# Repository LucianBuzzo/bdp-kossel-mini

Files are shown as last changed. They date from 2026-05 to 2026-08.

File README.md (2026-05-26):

# BDP Kossel Mini

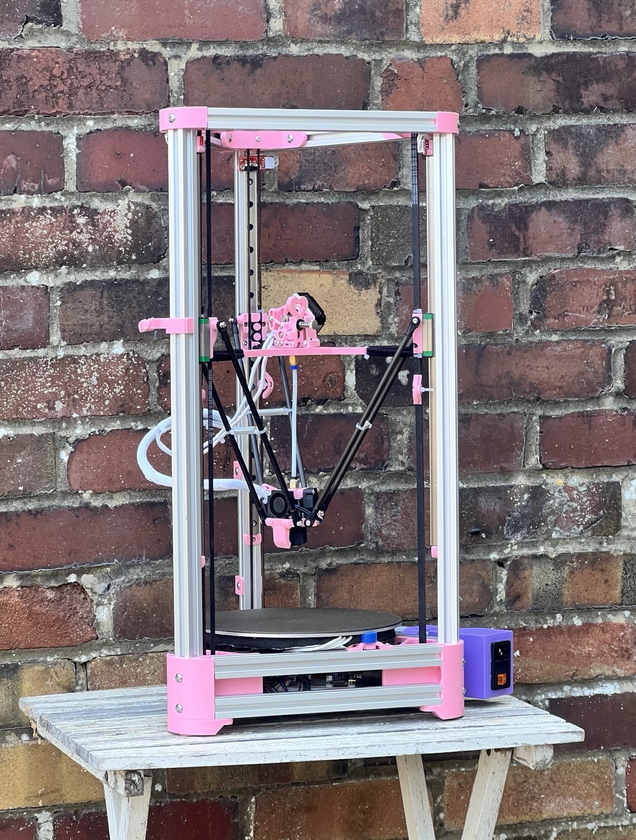
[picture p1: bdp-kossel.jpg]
BDP Kossel Mini delta printer


A modern take on the Kossel Mini delta printer using 2020 extrusions, running on an SKR Pico, and a Raspberry Pi Zero, powered by a meanwell UHP-350-24 PSU.

## Assembly

The major components of the printer are split into separate folders. Follow the instructions contained in each of them:
- [Chassis](./models/chassis/README.md)
- [Effector](./models/effector/README.md)
- [Extruder](./models/extruder/sherpa-extra-lovely/README.md)
- [Motion](./models/motion/README.md)
- [PSU](./models/PSU/README.md)

## Bill of Materials

The full bill of materials is compiled from component BOM CSV files in [`bom/`](./bom/).

See the generated [compiled BOM](./bom/README.md) or [combined CSV](./bom/combined.csv).

## Design Source and Exports

The canonical CAD source for this project is the linked Tinkercad design in each component README.

The STL files in this repository are exported from those Tinkercad designs and included for convenience so a known buildable version is available without needing to re-export the CAD.

To modify a part, update the relevant Tinkercad design, export new STL files, replace the files in this repository, and update the component README if the change affects print count, assembly, or the BOM.

## License

Original BDP Kossel Mini content is licensed under the [Creative Commons Attribution-ShareAlike 4.0 International License](./LICENSE).

Some included models are remixes or reused parts with their own license terms. See [THIRD_PARTY_LICENSES.md](./THIRD_PARTY_LICENSES.md) for attribution and per-file licensing.

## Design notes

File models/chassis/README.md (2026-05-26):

# Chassis

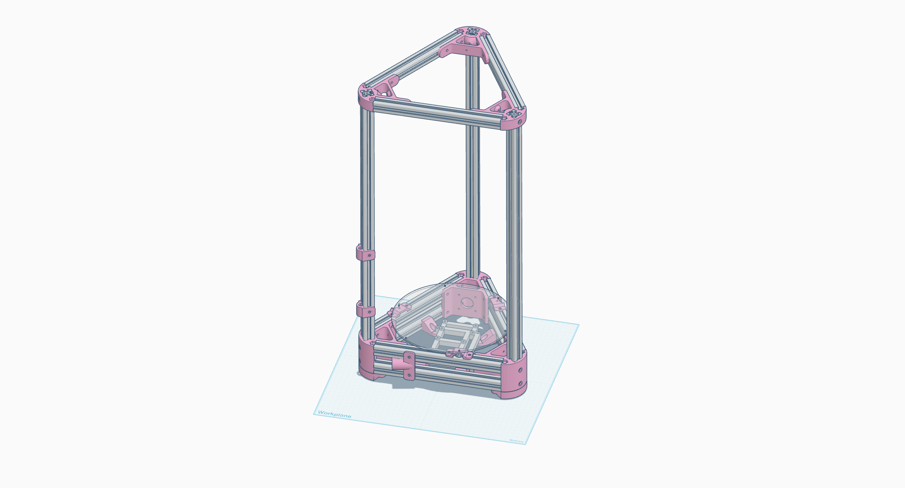
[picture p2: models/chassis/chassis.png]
Chassis


The chassis is designed around the original Kossel 2020 designs.
You'll need 3 x `frame-top.stl`, 3 x `frame-motor.stl` and 3 x `foot.stl` to print the frame.

For mounting the bed, print 3 x `bed-mount-base.stl` and 3 x `bed-mount-knob.stl`.

If you want to use the effector umbilical cable guides, print 2 x `cable-guide-tower.stl` and 1 x `cable-guide-base.stl`.

The electronics mount in the base, and are designed to fit the SKR Pico and a Raspberry Pi Zero. You'll need two `electronics-mount-front.stl` and two `electronics-mount-back.stl`. These could be the same file, but I haven't done the design work to make them the same yet.

The MCU mount plate is the "no inserts" variant of [Kanrog's Rook Mk1 design](https://www.printables.com/model/388353-rook-mk1-skr-pico-pi-zero-adapter/files).

## Bill of Materials

See the [chassis BOM](../../bom/chassis.csv) and the generated [compiled BOM](../../bom/README.md).

## Design Source

https://www.tinkercad.com/things/ggqOKI0i9KW-bdp-chassis

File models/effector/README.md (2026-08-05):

# Effector

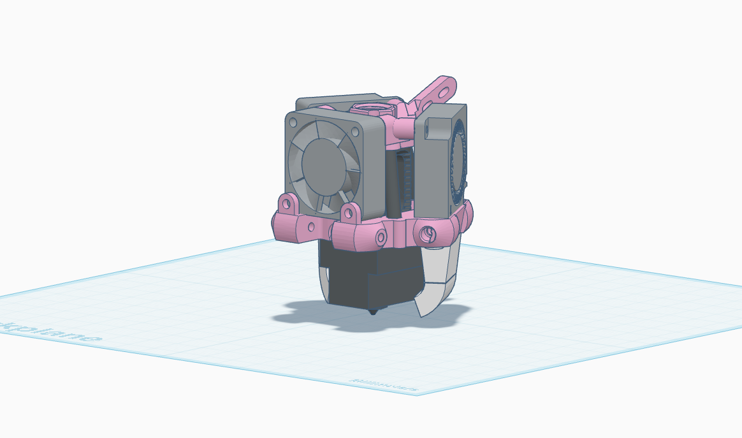
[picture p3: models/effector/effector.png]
Effector


The BDP effector is built around the original Kossel 2020 design, retaining the same arm spacing.
It's designed around the Triangle Lab Dragon Ace Volcano hotend ([This one specifically](https://jb3d.uk/product/dav/)), but could be adapted to support other hotends with the same mounting pattern by modifying the Z height of the cooling ducts.
Cooling is provided by a 3010 axial fan for the hotend, and two 3010 blower fans for part cooling.
Assembly also requires three 4mmx30mm Carbon Fiber Tubes.

## Bill of Materials

See the [effector BOM](../../bom/effector.csv) and the generated [compiled BOM](../../bom/README.md).

## Assembly Guide

1. Print the following parts:
    - `top-plate.stl` (x1)
    - `bottom-plate.stl` (x1)
    - `duct.stl` (x2)
    - `glue-up-jig.stl` (x1)
2. Cut the carbon fiber tubes to 30mm, and clean the ends with a file or sandpaper. Make sure to wear a mask and gloves when working with carbon fiber, as the dust is nasty and makes your skin itch! I recommend keeping everything wet when cutting and sanding to minimize dust.
3. Bolt the top and bottom plate to the glue up jig. This will keep the two plates perfectly parallel while you glue the carbon fiber tubes in place.
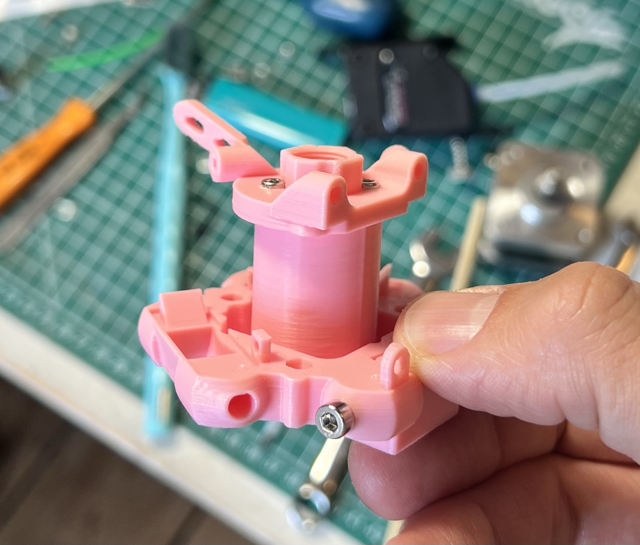
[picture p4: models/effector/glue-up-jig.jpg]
Glue up jig

4. Mix up your epoxy and apply a small amount to the tube socket in the top plate, and a small amount to the bottom end of the carbon fiber tube. Slide the tube in through the hole in the bottom plate and insert the tube into the socket in the top plate, ensuring it's firmly seated, then wipe away any excess epoxy. Repeat for all three tubes.
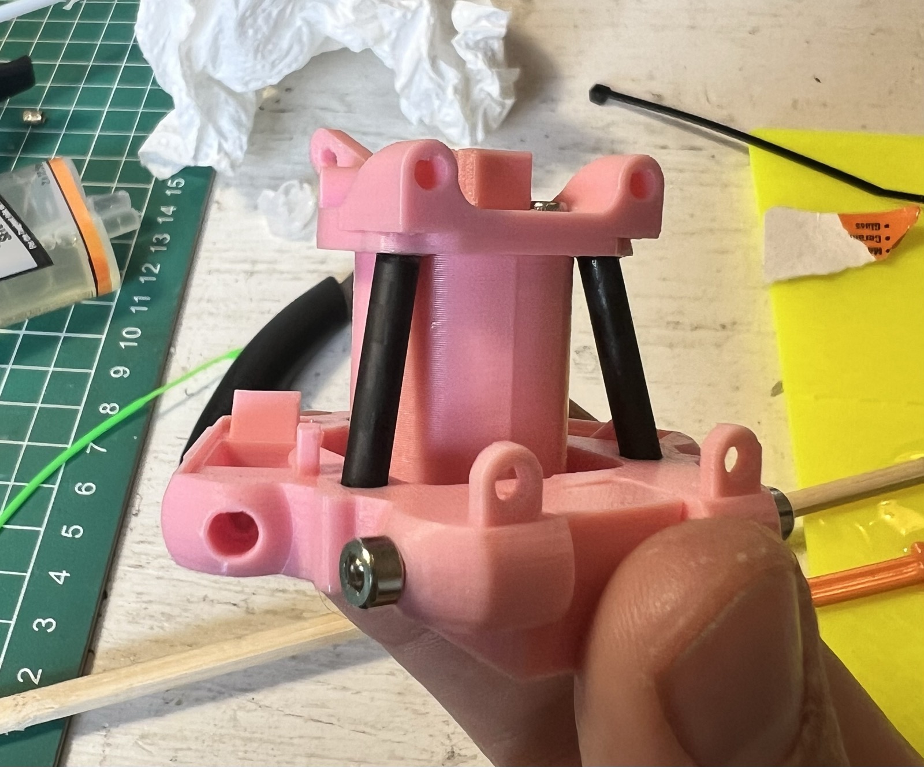
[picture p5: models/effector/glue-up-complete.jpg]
Glue up complete

5. Let the epoxy cure for at least 24 hours, then remove the glue up jig.
6. Press the M3 heat set inserts into the lateral con rod sockets on the bottom plate.
7. Press the M2 heat set inserts into the duct mounting holes on the underside of the bottom plate.
8. Mount the hotend to the top plate using the M2.5 hex bolts. You will need to route the hotend wires through the gap between the top and bottom plates, with each wire going either side of the carbon fiber tube.
9. Mount the axial fan to the bottom plate using the M3x12mm hex bolts and the M3 square nuts.
10. Mount the blower fans to the bottom plate using the M2.5 hex bolts.
11. Mount the ducts to the bottom plate using the M2 hex bolts.
12. Route the fan and thermistor wires through the gap between the top and bottom plates. 
13. Finish with some nice cable sleeve and zip tie to the cable relief points on the top plate, and you're done!

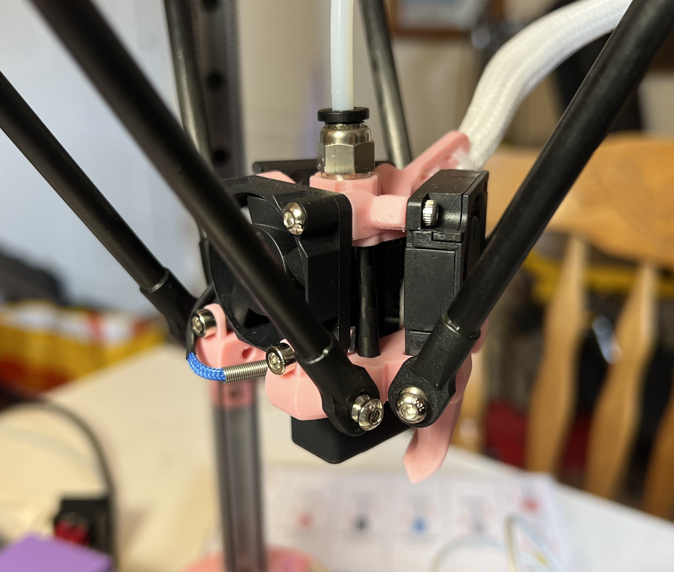
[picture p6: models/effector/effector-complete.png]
Assembled effector


## Design Source

https://www.tinkercad.com/things/bwVs2w1J2AP-bdp-effector

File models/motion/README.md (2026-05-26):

# Motion System

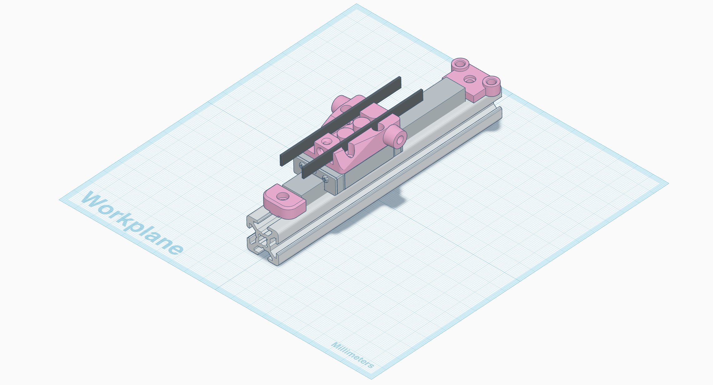
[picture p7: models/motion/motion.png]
Motion system render


The motion system on the BDP uses 6mm belt, 300mm long MGN12H linear rails, mechanical endstop switches and on-belt tensioners.

You will need to print 3 each of `carriage.stl`, `tensioner.stl`, `endstop-mount.stl` and `mgn12-endstop.stl`.

The carriages use m3 6mm heat seat inserts, and the endstop mounts use m3 4mm heat seat inserts. The endstops are designed around the RepRap/makerbot style endstop switches.

The MGN12 endstop is [vale075's design from printables](https://www.printables.com/model/345798-mgn12-rail-stopperendstop), and the tensioner is [Kiolia's universal adjustable belt tensioner](https://www.printables.com/model/157225-universal-adjustable-belt-tensioner), also from printables.

## Bill of Materials

See the [motion system BOM](../../bom/motion.csv) and the generated [compiled BOM](../../bom/README.md).

## Design Source

https://www.tinkercad.com/things/a9pKTf634uS-bdp-motion-system

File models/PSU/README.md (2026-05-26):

# PSU

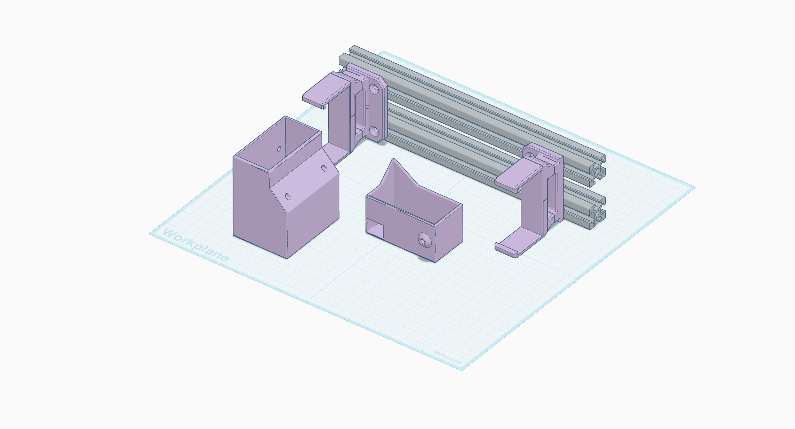
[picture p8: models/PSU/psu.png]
PSU Mount


This mount is designed to hold the Meanwell UHP-350-24 PSU, which is a 350W 24V power supply. It's a bit of a beast, but it has more than enough power for our needs, and it's also very efficient and reliable. The design here is a remix of [JP3d's design for the the Ratrig V-minion](https://www.printables.com/model/121864-meanwell-uhp-350-24-mount-for-ratrig-v-minion-3d-p/files), but modified to fit the Kossel mini frame spacing.

You'll need to print one `endcap-ac.stl` and one `endcap-dc.stl` for the two ends of the PSU, and `mount-left.stl` and `mount-right.stl` for the mounting brackets. The mount is designed to be bolted to the frame using M5x8mm button head hex bolts and M5 T-nuts. I used 2 M3 heat set inserts in the AC endcap and 1 M3 heat set insert in the DC endcap, but you could also use M3 bolts and nuts if you prefer.

## Bill of Materials

See the [PSU BOM](../../bom/psu.csv) and the generated [compiled BOM](../../bom/README.md).

## Design Source

https://www.tinkercad.com/things/7UkfZWxoEYF-kossel-mini-uhp-350-24-psu-mount

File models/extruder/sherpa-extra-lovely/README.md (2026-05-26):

# Sherpa "Extra Lovely" Extruder

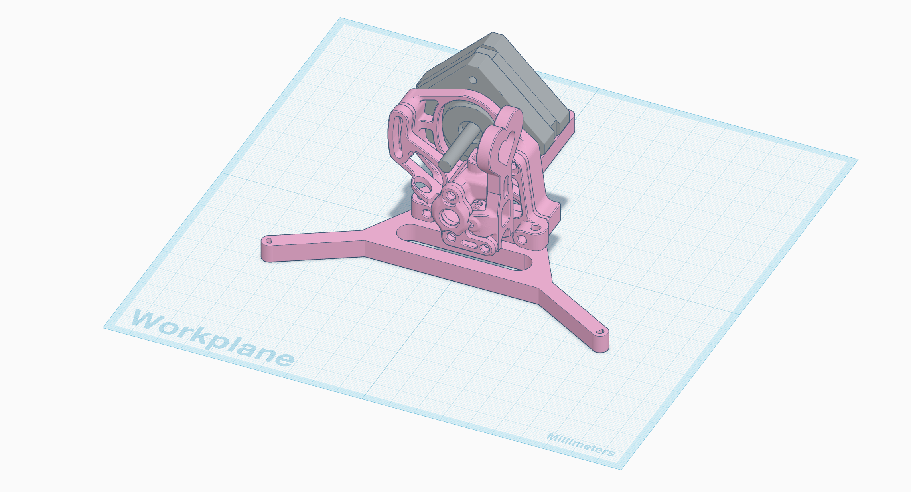
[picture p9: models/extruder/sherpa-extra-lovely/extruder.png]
Sherpa Extra Lovely


This is a remix of the [Sherpa Extra Heavy](https://www.printables.com/model/549890-sherpa-extra-heavy-with-nema17-update-2). 
I found that the original Sherpa Extra Heavy housing was too small for the [BMG gear kit](https://www.aliexpress.com/item/1005007720655144.html) I ordered, which seems to be a common issue with the Sherpa Extra Heavy design. This remix has a slightly larger housing (1.4mm) to accommodate the BMG gear kit, and also includes some aesthetic changes to make it more "lovely".

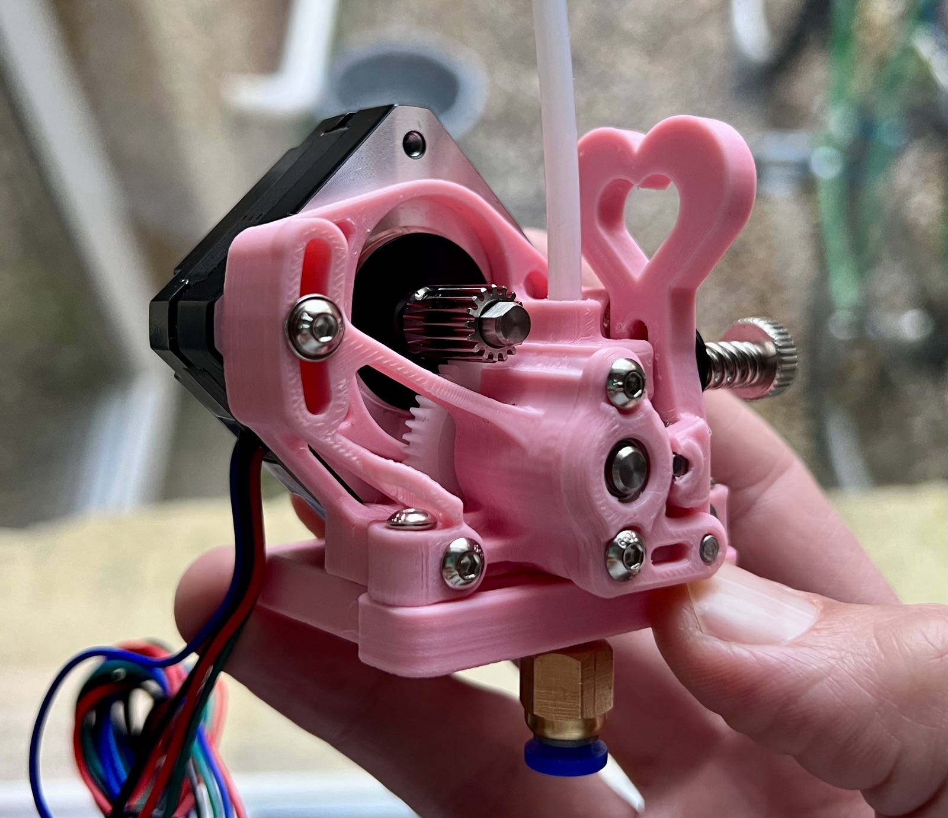
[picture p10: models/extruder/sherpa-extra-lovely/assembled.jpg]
Sherpa Extra Lovely - fully assembled


If you're flying the extruder, you'll need to print the `flying-extruder-mount.stl`. I suggest using hair elastics and zip ties to secure the mount to the carriages.

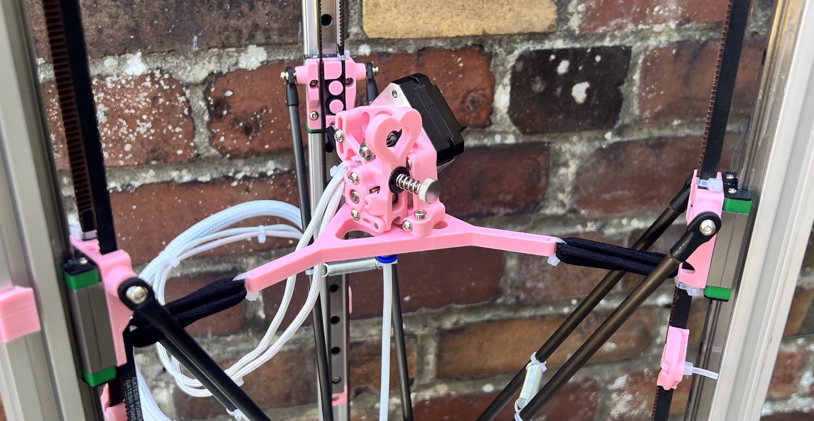
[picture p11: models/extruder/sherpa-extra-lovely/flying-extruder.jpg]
Sherpa Extra Lovely - flying extruder


I've also included a mounting assembly that will allow you to setup the extruder in a Bowden configuration, mounted to the outside of the frame at a 45 degree angle.
If you prefer this approach, print the `45deg-tower-mount.stl` and the `mounting-plate.stl`.

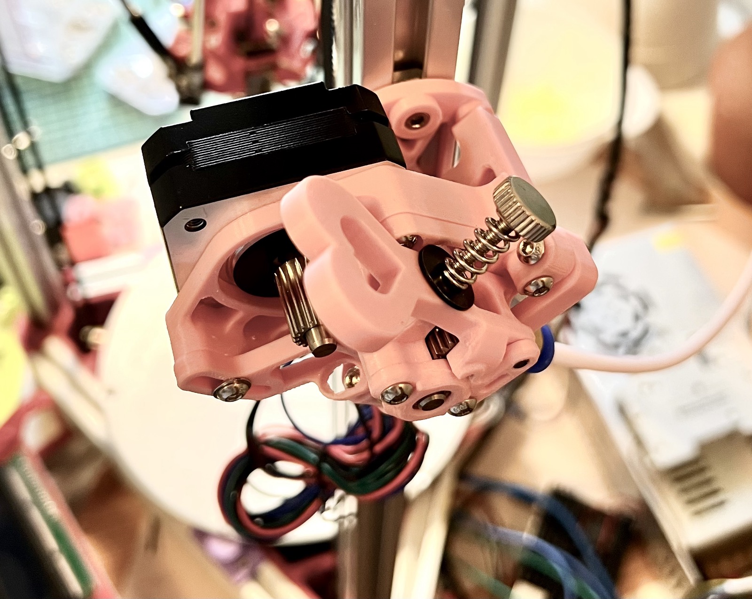
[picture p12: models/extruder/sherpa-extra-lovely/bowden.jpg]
Sherpa Extra Lovely - tower mounted


## Bill of Materials

See the [extruder BOM](../../../bom/extruder.csv) and the generated [compiled BOM](../../../bom/README.md).

## Design Source

https://www.tinkercad.com/things/eVswxnjzAfZ-sherpa-extra-lovely

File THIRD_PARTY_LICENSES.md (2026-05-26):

# Third-Party Licenses and Attribution

This repository includes original BDP Kossel Mini work and several remixed or reused model files.

Unless otherwise noted here, original BDP Kossel Mini content is licensed under the Creative Commons Attribution-ShareAlike 4.0 International License in `LICENSE`.

The files and folders below retain the license terms of their upstream sources.

## Extruder

Affected files:

- `models/extruder/sherpa-extra-lovely/45deg-tower-mount.stl`
- `models/extruder/sherpa-extra-lovely/flying-extruder-mount.stl`
- `models/extruder/sherpa-extra-lovely/housing-core.stl`
- `models/extruder/sherpa-extra-lovely/housing-front.stl`
- `models/extruder/sherpa-extra-lovely/housing-rear.stl`
- `models/extruder/sherpa-extra-lovely/idler-arm.stl`
- `models/extruder/sherpa-extra-lovely/mounting-plate.stl`

Source:

- Sherpa "Extra" Heavy with NEMA17 (Update 2)
- Author: HDz_designs
- URL: https://www.printables.com/model/549890-sherpa-extra-heavy-with-nema17-update-2
- Source license: CC-BY-NC

License for affected files: CC-BY-NC.

## Motion System

Affected file:

- `models/motion/mgn12-endstop.stl`

Source:

- MGN12 rail-stopper/endstop
- Author: vale075
- URL: https://www.printables.com/model/345798-mgn12-rail-stopperendstop
- Source license: GPL 3.0

License for affected file: GPL 3.0.

Affected file:

- `models/motion/tensioner.stl`

Source:

- Universal Adjustable Belt Tensioner
- Author: Kiolia
- URL: https://www.printables.com/model/157225-universal-adjustable-belt-tensioner
- Source license: CC-BY-NC

License for affected file: CC-BY-NC.

## PSU Mount

Affected files:

- `models/PSU/endcap-ac.stl`
- `models/PSU/endcap-dc.stl`
- `models/PSU/mount-left.stl`
- `models/PSU/mount-right.stl`

Source:

- Meanwell UHP-350-24 mount for Ratrig V-Minion 3D Printer
- Author: JP3d
- URL: https://www.printables.com/model/121864-meanwell-uhp-350-24-mount-for-ratrig-v-minion-3d-p/files
- Source license: CC-BY-NC-SA

License for affected files: CC-BY-NC-SA.

## Chassis

Affected file:

- `models/chassis/mcu-mount.stl`

Source:

- Rook MK1 SKR Pico & Pi Zero Adapter
- Author: Kanrog Creations
- URL: https://www.printables.com/model/388353-rook-mk1-skr-pico-pi-zero-adapter/files
- Source license: CC-BY

License for affected file: CC-BY. This is compatible with the repository's CC-BY-SA license for original content, but the attribution is retained here for clarity.

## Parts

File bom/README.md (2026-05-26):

# Bill of Materials

This BOM is generated from the component CSV files in this directory. Do not edit it directly.

To update it, edit the relevant component CSV and run:

```sh
python3 scripts/generate-bom.py
```

The generated combined CSV is available at [`combined.csv`](./combined.csv).

## Combined BOM

| Part | Quantity | Unit | Spec | Used in | Notes |
| --- | --- | --- | --- | --- | --- |
| 2020 extrusion | 9 | pcs | 240mm | chassis |  |
| 2020 extrusion | 3 | pcs | 600mm | chassis |  |
| 3010 axial fan | 1 | pcs |  | effector |  |
| 3010 blower fan | 2 | pcs |  | effector |  |
| Aluminum build plate | 1 | pcs | 220mm | printer |  |
| BMG gear kit | 1 | set |  | extruder |  |
| BTT SKR Pico | 1 | pcs |  | printer |  |
| C14 IEC power inlet | 1 | pcs |  | psu | or similar |
| Carbon fiber tube | 3 | pcs | 4mm x 30mm | effector |  |
| Delta connecting arm | 6 | pcs | 235mm | motion |  |
| GT2 belt | 4 | m | 6mm | motion | enough to cut into 3 equal lengths |
| JST connectors | 1 | as needed |  | printer |  |
| M2 heat set insert | 4 | pcs | M2x2.5x3.2mm | effector |  |
| M2.5x6mm hex bolt | 16 | pcs |  | chassis, effector | chassis: for mounting electronics |
| M2x4mm hex bolt | 4 | pcs |  | effector |  |
| M3 heat set insert | 2 | pcs | M3x4mm | extruder |  |
| M3 heat set insert | 6 | pcs | M3x4mm brass | motion |  |
| M3 heat set insert | 3 | pcs | M3x5mm | psu | 2 for AC endcap and 1 for DC endcap |
| M3 heat set insert | 3 | pcs | M3x6mm | extruder |  |
| M3 heat set insert | 6 | pcs | M3x6mm brass | motion |  |
| M3 heat set insert | 6 | pcs | M3x6x5mm | effector |  |
| M3 hex nut | 3 | pcs |  | chassis | for the bed mounts |
| M3 square nut | 2 | pcs |  | effector |  |
| M3 T-nut | 6 | pcs |  | chassis |  |
| M3x12mm hex bolt | 2 | pcs |  | effector |  |
| M3x14mm hex bolt | 2 | pcs |  | effector |  |
| M3x16mm button socket head cap screw | 2 | pcs |  | extruder |  |
| M3x18mm button socket head cap screw | 2 | pcs |  | extruder |  |
| M3x6mm hex bolt | 15 | pcs |  | motion, psu |  |
| M3x8mm button socket head cap screw | 2 | pcs |  | extruder |  |
| M3x8mm hex bolt | 28 | pcs |  | chassis, motion |  |
| M5 T-nut | 47 | pcs |  | chassis, psu |  |
| M5x8mm button head hex bolt | 47 | pcs |  | chassis, psu |  |
| Meanwell UHP-350-24 PSU | 1 | pcs | 350W 24V | psu |  |
| MGN12H linear rail | 3 | pcs | 300mm | motion |  |
| Paracord | 1 | as needed |  | printer | for cable management |
| Raspberry Pi Zero W | 1 | pcs |  | printer |  |
| RepRap mechanical endstop switch | 3 | pcs |  | motion |  |
| Silicone heater | 1 | pcs | 24V | printer |  |
| Silicone wire | 1 | as needed | 18AWG | printer | for power wiring |
| Silicone wire | 1 | as needed | 24AWG | printer | for signal wiring |
| Split sleeving | 1 | as needed | 1/4 inch | printer |  |
| Spring steel shim washer | 1 | pcs | 7mm OD x 5mm ID x 0.5mm thick | extruder |  |
| Thermistor | 1 | pcs | 3950 | printer |  |
| Triangle Lab Dragon Ace Volcano hotend | 1 | pcs |  | effector |  |
| Two part epoxy | 1 | set |  | effector |  |
| Zip tie | 3 | pcs | 4mm | motion |  |

## Component BOMs

### Chassis

| Part | Quantity | Unit | Spec | Notes |
| --- | --- | --- | --- | --- |
| 2020 extrusion | 9 | pcs | 240mm |  |
| 2020 extrusion | 3 | pcs | 600mm |  |
| M5 T-nut | 43 | pcs |  |  |
| M3 T-nut | 6 | pcs |  |  |
| M3 hex nut | 3 | pcs |  | for the bed mounts |
| M5x8mm button head hex bolt | 43 | pcs |  |  |
| M3x8mm hex bolt | 10 | pcs |  |  |
| M2.5x6mm hex bolt | 8 | pcs |  | for mounting electronics |

### Effector

| Part | Quantity | Unit | Spec | Notes |
| --- | --- | --- | --- | --- |
| Triangle Lab Dragon Ace Volcano hotend | 1 | pcs |  |  |
| 3010 axial fan | 1 | pcs |  |  |
| 3010 blower fan | 2 | pcs |  |  |
| Carbon fiber tube | 3 | pcs | 4mm x 30mm |  |
| Two part epoxy | 1 | set |  |  |
| M3 heat set insert | 6 | pcs | M3x6x5mm |  |
| M2 heat set insert | 4 | pcs | M2x2.5x3.2mm |  |
| M3 square nut | 2 | pcs |  |  |
| M2.5x6mm hex bolt | 8 | pcs |  |  |
| M2x4mm hex bolt | 4 | pcs |  |  |
| M3x14mm hex bolt | 2 | pcs |  |  |
| M3x12mm hex bolt | 2 | pcs |  |  |

### Extruder

| Part | Quantity | Unit | Spec | Notes |
| --- | --- | --- | --- | --- |
| BMG gear kit | 1 | set |  |  |
| M3x18mm button socket head cap screw | 2 | pcs |  |  |
| M3x16mm button socket head cap screw | 2 | pcs |  |  |
| M3x8mm button socket head cap screw | 2 | pcs |  |  |
| Spring steel shim washer | 1 | pcs | 7mm OD x 5mm ID x 0.5mm thick |  |
| M3 heat set insert | 2 | pcs | M3x4mm |  |
| M3 heat set insert | 3 | pcs | M3x6mm |  |

### Motion

| Part | Quantity | Unit | Spec | Notes |
| --- | --- | --- | --- | --- |
| GT2 belt | 4 | m | 6mm | enough to cut into 3 equal lengths |
| MGN12H linear rail | 3 | pcs | 300mm |  |
| RepRap mechanical endstop switch | 3 | pcs |  |  |
| Delta connecting arm | 6 | pcs | 235mm |  |
| M3x8mm hex bolt | 18 | pcs |  |  |
| M3x6mm hex bolt | 12 | pcs |  |  |
| M3 heat set insert | 6 | pcs | M3x6mm brass |  |
| M3 heat set insert | 6 | pcs | M3x4mm brass |  |
| Zip tie | 3 | pcs | 4mm |  |

### Printer

| Part | Quantity | Unit | Spec | Notes |
| --- | --- | --- | --- | --- |
| BTT SKR Pico | 1 | pcs |  |  |
| Raspberry Pi Zero W | 1 | pcs |  |  |
| Aluminum build plate | 1 | pcs | 220mm |  |
| Silicone heater | 1 | pcs | 24V |  |
| Thermistor | 1 | pcs | 3950 |  |
| Silicone wire | 1 | as needed | 18AWG | for power wiring |
| Silicone wire | 1 | as needed | 24AWG | for signal wiring |
| JST connectors | 1 | as needed |  |  |
| Split sleeving | 1 | as needed | 1/4 inch |  |
| Paracord | 1 | as needed |  | for cable management |

### PSU

| Part | Quantity | Unit | Spec | Notes |
| --- | --- | --- | --- | --- |
| Meanwell UHP-350-24 PSU | 1 | pcs | 350W 24V |  |
| C14 IEC power inlet | 1 | pcs |  | or similar |
| M5 T-nut | 4 | pcs |  |  |
| M5x8mm button head hex bolt | 4 | pcs |  |  |
| M3 heat set insert | 3 | pcs | M3x5mm | 2 for AC endcap and 1 for DC endcap |
| M3x6mm hex bolt | 3 | pcs |  |  |

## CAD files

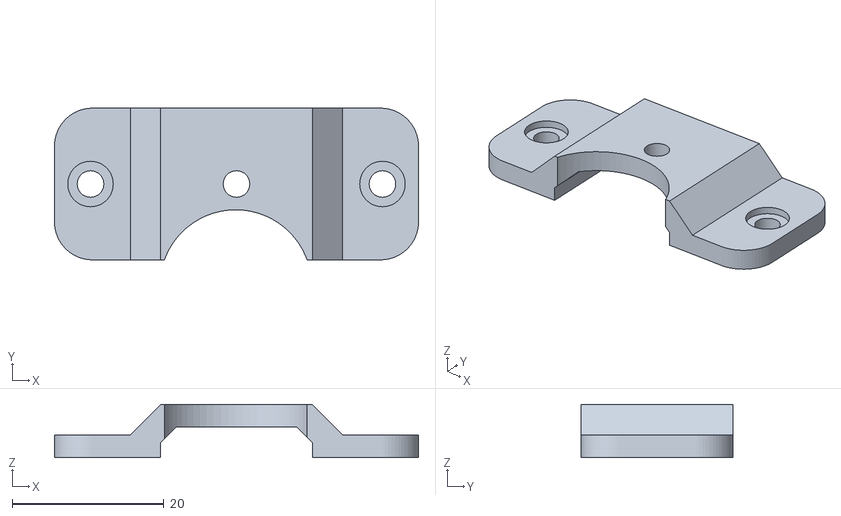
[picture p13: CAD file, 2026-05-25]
models/chassis/bed-mount-base.stl
48.0 x 20.0 x 7.00

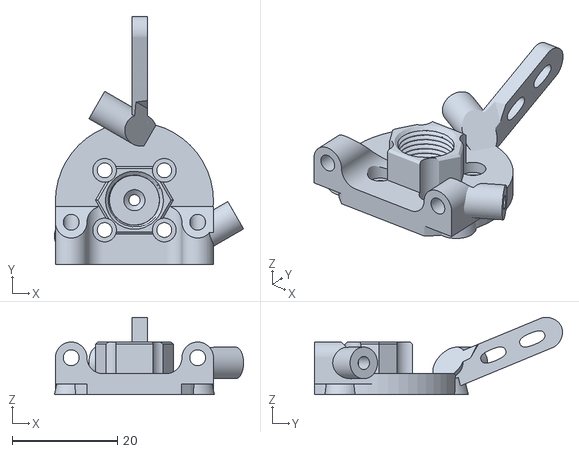
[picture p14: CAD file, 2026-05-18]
models/effector/top-plate.stl
35.9 x 47.1 x 14.7

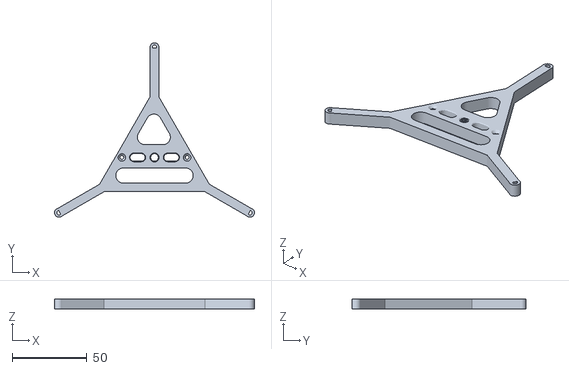
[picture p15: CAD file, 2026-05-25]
models/extruder/sherpa-extra-lovely/flying-extruder-mount.stl
133.4 x 116.3 x 7.00

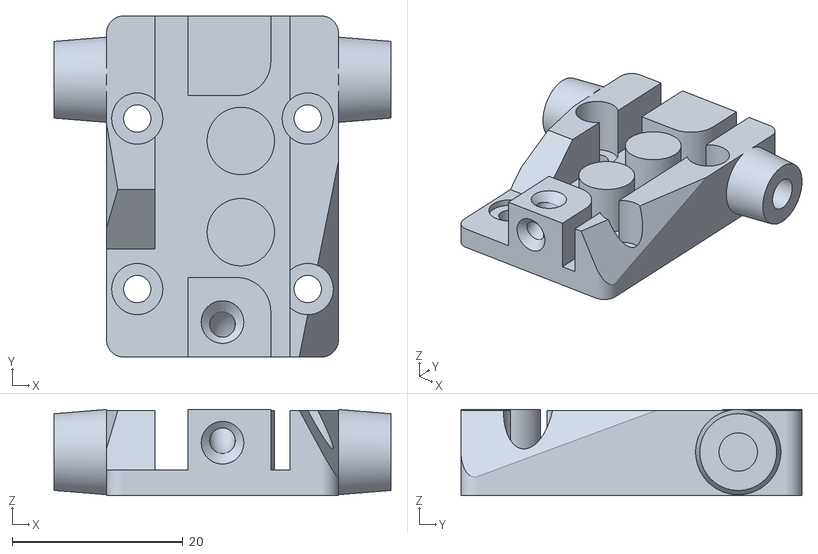
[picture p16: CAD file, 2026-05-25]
models/motion/carriage.stl
39.5 x 40.0 x 10.1

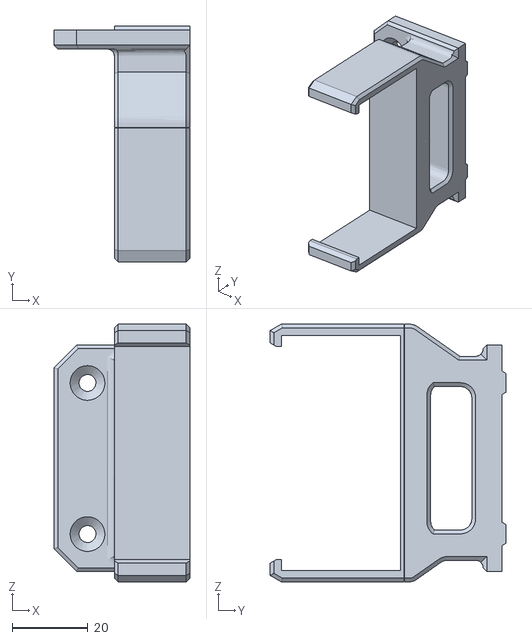
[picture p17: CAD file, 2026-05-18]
models/PSU/Kossel mini UHP-350-24 PSU mount - bracket right.stl
36.0 x 62.4 x 68.3

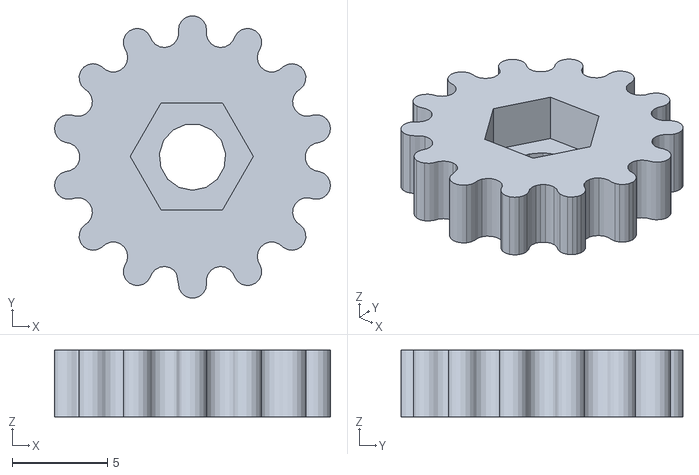
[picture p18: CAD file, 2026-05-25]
models/chassis/bed-mount-knob.stl
14.5 x 14.8 x 3.50

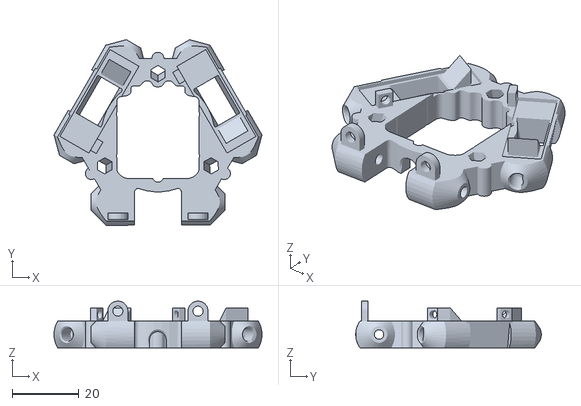
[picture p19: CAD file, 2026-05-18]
models/effector/bottom-plate.stl
62.3 x 55.6 x 14.0

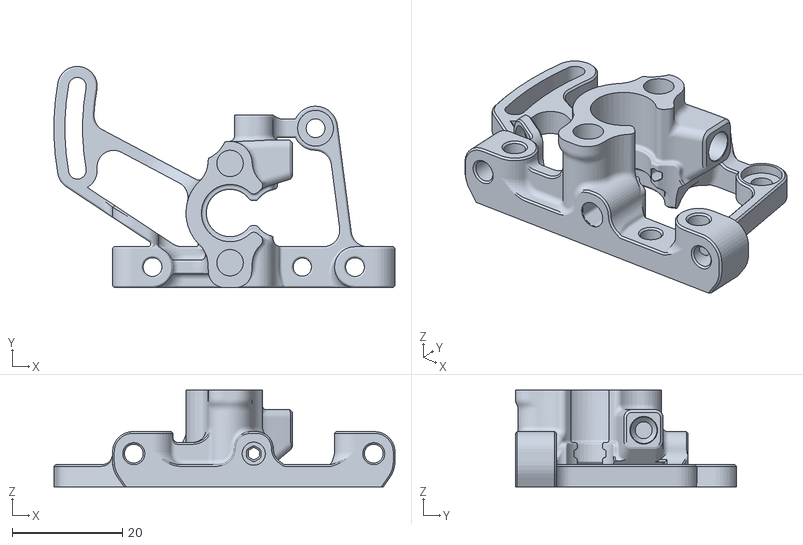
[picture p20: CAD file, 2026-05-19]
models/extruder/sherpa-extra-lovely/housing-rear.stl
61.8 x 40.1 x 17.5

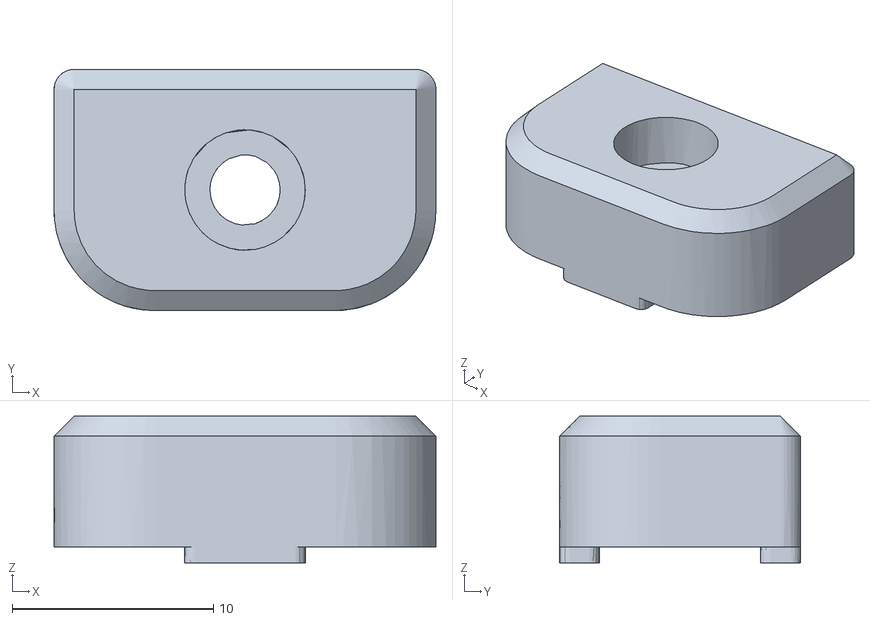
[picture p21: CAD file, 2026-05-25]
models/motion/mgn12-endstop.stl
19.0 x 12.0 x 7.30

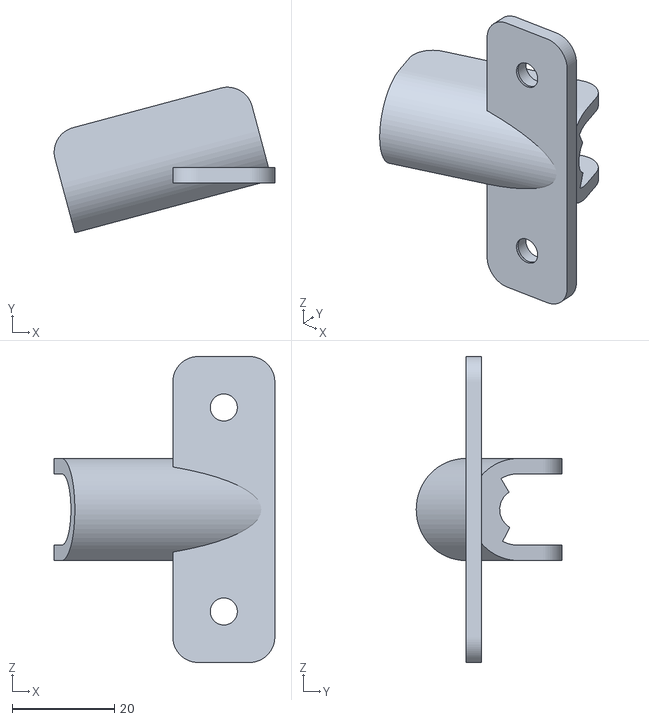
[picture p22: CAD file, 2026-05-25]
models/chassis/cable-guide-base.stl
43.3 x 28.5 x 60.0

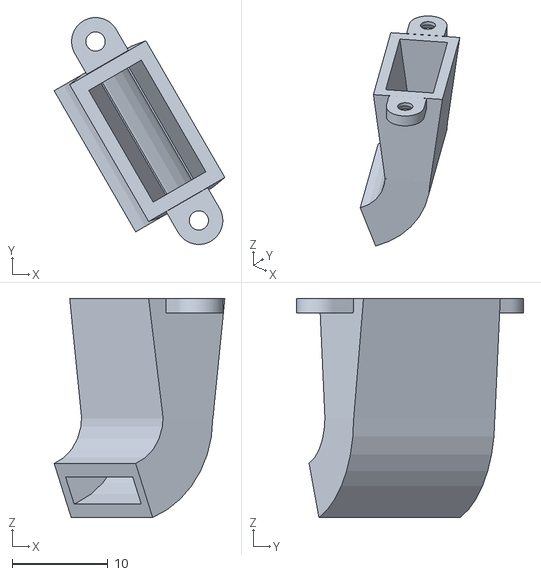
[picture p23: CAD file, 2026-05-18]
models/effector/duct.stl
17.8 x 23.7 x 22.8

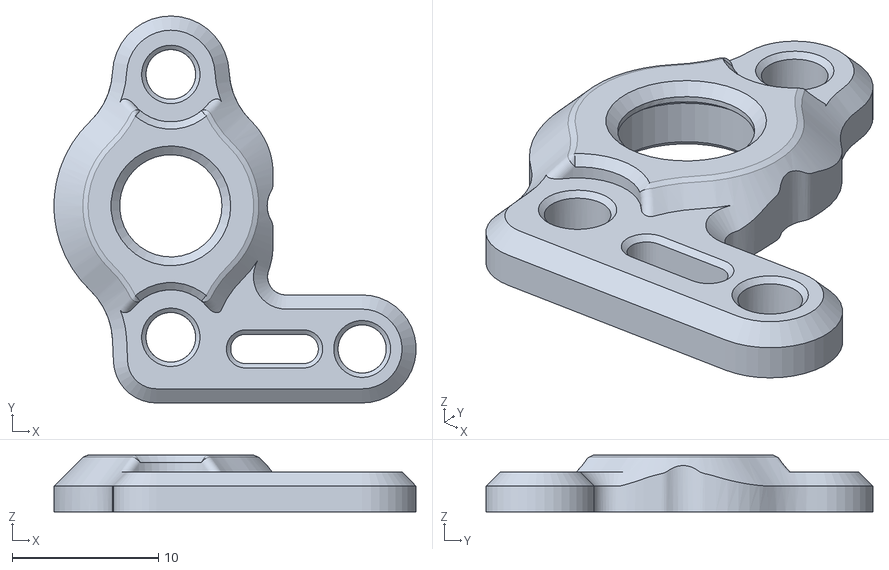
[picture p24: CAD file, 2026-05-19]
models/extruder/sherpa-extra-lovely/housing-front.stl
24.8 x 26.5 x 3.90

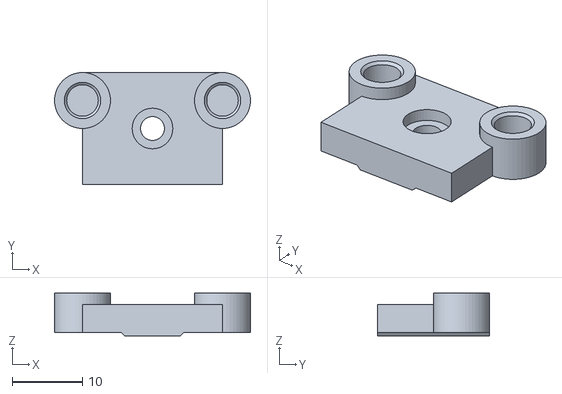
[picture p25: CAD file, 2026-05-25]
models/motion/endstop-mount.stl
28.0 x 16.0 x 6.10

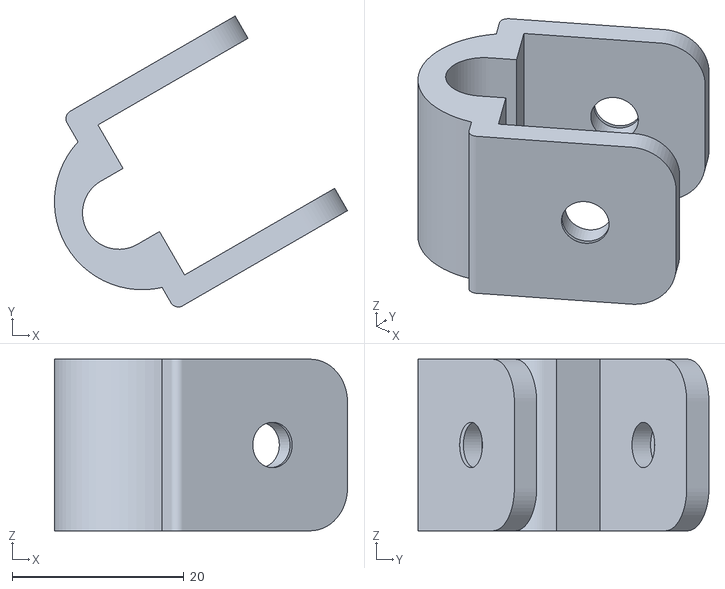
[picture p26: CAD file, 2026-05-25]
models/chassis/cable-guide-tower.stl
34.2 x 33.9 x 20.0

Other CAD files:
models/PSU/mount-right.stl
models/effector/glue-up-jig.stl
models/extruder/sherpa-extra-lovely/housing-core.stl
models/PSU/Kossel mini UHP-350-24 PSU mount - bracket left.stl
models/PSU/endcap-ac.stl
models/PSU/endcap-dc.stl
models/chassis/bed-mount.stl
models/chassis/electronics-mount-back.stl
models/chassis/electronics-mount-front.stl
models/chassis/foot.stl
models/chassis/frame-motor.stl
models/chassis/frame-top.stl
models/chassis/mcu-mount.stl
models/extruder/sherpa-extra-lovely/45deg-tower-mount.stl
models/extruder/sherpa-extra-lovely/idler-arm.stl
models/extruder/sherpa-extra-lovely/mounting-plate.stl
models/motion/tensioner.stl

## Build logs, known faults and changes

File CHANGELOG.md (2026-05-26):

# Changelog

## [0.2.0](https://github.com/LucianBuzzo/bdp-kossel-mini/compare/bdp-kossel-mini-v0.1.0...bdp-kossel-mini-v0.2.0) (2026-05-26)

### Features

* Add BOM and image to README ([9aea29d](https://github.com/LucianBuzzo/bdp-kossel-mini/commit/9aea29d0380dfaac2b9b13dd6a96f1588a7735b0))
* add docs for sherpa extra lovely ([7b14988](https://github.com/LucianBuzzo/bdp-kossel-mini/commit/7b14988829f8ac5e54a3527301e4df052114829e))
* add documentation for effector ([539f42d](https://github.com/LucianBuzzo/bdp-kossel-mini/commit/539f42d361f5f9173ba26dd6d07fbed62e9857d7))
* add documentation for PSU mount ([400563f](https://github.com/LucianBuzzo/bdp-kossel-mini/commit/400563fb2fc3cb0d70cf1fcf82dfc2b957361204))
* add generated BOM workflow ([bece13f](https://github.com/LucianBuzzo/bdp-kossel-mini/commit/bece13f79280f1697daedbe9c46e81ff90516efa))
* **chassis:** clean up Chassis section and add README ([9bc84d1](https://github.com/LucianBuzzo/bdp-kossel-mini/commit/9bc84d1e341ea7168b7844b93e71332d6b28beae))
* clarify CAD source and add RP action ([506ac95](https://github.com/LucianBuzzo/bdp-kossel-mini/commit/506ac95c9404a02082a0877daf12c937684eb1b0))
* update chassis image and add TC link ([740c9e1](https://github.com/LucianBuzzo/bdp-kossel-mini/commit/740c9e1ef3e8b9e7890240d3668edcb530d6eca4))
* update documents for motion system ([bd117aa](https://github.com/LucianBuzzo/bdp-kossel-mini/commit/bd117aa1c6b0dacd15fa4f01f3003e2848381cb6))

### Bug Fixes

* add delta arms to bom ([531fc01](https://github.com/LucianBuzzo/bdp-kossel-mini/commit/531fc014c25644f50e2d414cd0ad025126004ba4))
* add flying extruder plate files ([4d02a54](https://github.com/LucianBuzzo/bdp-kossel-mini/commit/4d02a543df39163c6cefddf8ebcd52d83e647551))
* correct 2020 bom quantiy ([927aee5](https://github.com/LucianBuzzo/bdp-kossel-mini/commit/927aee5cf736f0eec1e3456c75aa4b5b7151060f))
* restrict image size ([5091e32](https://github.com/LucianBuzzo/bdp-kossel-mini/commit/5091e32bc51370889dde773a679760c1a84e8cb4))
* update chassis models and guide ([87c3c29](https://github.com/LucianBuzzo/bdp-kossel-mini/commit/87c3c2932948081af35e79c1c145ce151044c655))
* use correct image path in README ([f69d8ca](https://github.com/LucianBuzzo/bdp-kossel-mini/commit/f69d8cab5311dfb630a5f5376d9e48bcc291a996))

## Changelog

All notable changes to this project will be documented in this file.

This project uses [release-please](https://github.com/googleapis/release-please) to generate release notes from Conventional Commits.

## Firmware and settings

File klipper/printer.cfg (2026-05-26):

[mcu]
# This config targets the BIGTREETECH SKR Pico V1.0.
# Replace this with the stable by-id path for your board after flashing Klipper.
serial: /dev/serial/by-id/usb-Klipper_rp2040_REPLACE_WITH_YOUR_ID-if00

[printer]
kinematics: delta
max_velocity: 200
max_accel: 3000
max_z_velocity: 200
max_z_accel: 3000
square_corner_velocity: 5.0
#delta_radius: 105
print_radius: 90
minimum_z_position: -20

[delta_calibrate]
radius: 90

[stepper_a]
step_pin: gpio11
dir_pin: !gpio10
enable_pin: !gpio12
microsteps: 16
rotation_distance: 40
endstop_pin: ^gpio4
#position_endstop: 210
#arm_length: 232.00

[tmc2209 stepper_a]
uart_pin: gpio9
tx_pin: gpio8
uart_address: 0
run_current: 0.580
stealthchop_threshold: 999999

[stepper_b]
step_pin: gpio6
dir_pin: !gpio5
enable_pin: !gpio7
microsteps: 16
rotation_distance: 40
endstop_pin: ^gpio3
#position_endstop: 210
#arm_length: 232.00

[tmc2209 stepper_b]
uart_pin: gpio9
tx_pin: gpio8
uart_address: 2
run_current: 0.580
stealthchop_threshold: 999999

[stepper_c]
step_pin: gpio19
dir_pin: gpio28
enable_pin: !gpio2
microsteps: 16
rotation_distance: 40
endstop_pin: ^gpio25
#position_endstop: 210
#arm_length: 232.00

[tmc2209 stepper_c]
uart_pin: gpio9
tx_pin: gpio8
uart_address: 1
run_current: 0.580
stealthchop_threshold: 999999

[extruder]
step_pin: gpio14
dir_pin: !gpio13
enable_pin: !gpio15
microsteps: 16
rotation_distance: 32.51
nozzle_diameter: 0.400
filament_diameter: 1.750
heater_pin: gpio23
sensor_type: EPCOS 100K B57560G104F
sensor_pin: gpio27
control: pid
pid_Kp: 22.20
pid_Ki: 1.08
pid_Kd: 114.00
min_temp: 0
max_temp: 275

[tmc2209 extruder]
uart_pin: gpio9
tx_pin: gpio8
uart_address: 3
run_current: 0.650
stealthchop_threshold: 999999

[verify_heater extruder]
# I'm tired boss
check_gain_time: 90  # Default is 60

[heater_bed]
heater_pin: gpio21
sensor_type: EPCOS 100K B57560G104F
sensor_pin: gpio26
#control: watermark
min_temp: 0
max_temp: 120

[verify_heater heater_bed]
# The maximum "cumulative temperature error" before raising an error.
# Default is 120.
max_error: 300
# This controls how long it takes for the heater to check if it's
# actually heating. Increase this for slow-heating beds (e.g., to 120-180).
# Default is 60 for heater_bed.
check_gain_time: 120
hysteresis: 5
heating_gain: 2




[fan]
pin: gpio17

[heater_fan hotend_fan]
pin: gpio18
heater: extruder
heater_temp: 50.0

[probe]
pin: ^gpio22
x_offset: 9.40
y_offset: -9.00
#z_offset: 4.160
speed: 5.0
samples: 1

[bed_mesh]
speed: 50
horizontal_move_z: 5
mesh_radius: 80
mesh_origin: 0,0
round_probe_count: 5


[gcode_arcs]
resolution: 0.1

[display_status]
[pause_resume]
[exclude_object]
[virtual_sdcard]
path: ~/printer_data/gcodes

[temperature_sensor raspberry_pi]
sensor_type: temperature_host
min_temp: 10
max_temp: 100

[temperature_sensor skr_pico]
sensor_type: temperature_mcu
min_temp: 0
max_temp: 100

[neopixel board_neopixel]
pin: gpio24
chain_count: 1
color_order: GRB
initial_RED: 0.3
initial_GREEN: 0.3
initial_BLUE: 0.3


[gcode_macro PAUSE]
description: Pause the actual running print
rename_existing: BASE_PAUSE
gcode:
    BASE_PAUSE
    G91
    G1 E-3 F2100
    G1 Z10 F3000
    G90
    G1 X0 Y0 Z50 F6000  ; park high in center

[gcode_macro RESUME]
description: Resume the actual running print
rename_existing: BASE_RESUME
gcode:
    G91
    G1 E1 F2100
    G90
    BASE_RESUME

[gcode_macro CANCEL_PRINT]
description: Cancel the actual running print
rename_existing: BASE_CANCEL_PRINT
gcode:
    TURN_OFF_HEATERS
    G91
    G1 Z10 F3000
    G90
    G1 X0 Y0 Z50 F6000  ; park high in center
    CLEAR_PAUSE
    BASE_CANCEL_PRINT

[gcode_macro FULL_CALIBRATE]
description: Calibrate delta and bed mesh and save config
gcode:
    TURN_OFF_HEATERS
    G28
    DELTA_CALIBRATE
    BED_MESH_CALIBRATE
    SAVE_CONFIG

# Override "wait for bed heat" with more tolerant behaviour
[gcode_macro M190]
rename_existing: M190.1
gcode:
  {% set target = params.S|float %}
  SET_HEATER_TEMPERATURE HEATER=heater_bed TARGET={target}
  TEMPERATURE_WAIT SENSOR=heater_bed MINIMUM={target - 1.5}

#*# <---------------------- SAVE_CONFIG ---------------------->
#*# DO NOT EDIT THIS BLOCK OR BELOW. The contents are auto-generated.
#*#
#*# [probe]
#*# z_offset = 4.139
#*#
#*# [printer]
#*# delta_radius = 118.702195
#*#
#*# [heater_bed]
#*# control = pid
#*# pid_kp = 58.346
#*# pid_ki = 0.652
#*# pid_kd = 1306.213
#*#
#*# [stepper_a]
#*# angle = 211.496775
#*# arm_length = 232.000000
#*# position_endstop = 216.084748
#*#
#*# [stepper_b]
#*# angle = 331.265405
#*# arm_length = 232.000000
#*# position_endstop = 218.638439
#*#
#*# [stepper_c]
#*# angle = 90.000000
#*# arm_length = 232.000000
#*# position_endstop = 214.754377
#*#
#*# [bed_mesh default]
#*# version = 1
#*# points =
#*# 	  0.117820, 0.117820, 0.117820, 0.117820, 0.117820
#*# 	  0.326635, 0.326635, 0.172205, -0.046581, -0.046581
#*# 	  0.211698, 0.138872, 0.034594, -0.124350, -0.372990
#*# 	  0.134813, 0.134813, -0.013133, -0.136535, -0.136535
#*# 	  0.077991, 0.077991, 0.077991, 0.077991, 0.077991
#*# x_count = 5
#*# y_count = 5
#*# mesh_x_pps = 2
#*# mesh_y_pps = 2
#*# algo = lagrange
#*# tension = 0.2
#*# min_x = -80.0
#*# max_x = 80.0
#*# min_y = -80.0
#*# max_y = 80.0
#*#
#*# [delta_calibrate]
#*# height0 = 4.139
#*# height0_pos = 16986.000,17127.000,16846.000
#*# height1 = 4.139
#*# height1_pos = 21093.000,21010.000,14425.000
#*# height2 = 4.139
#*# height2_pos = 16453.000,23598.000,16236.000
#*# height3 = 4.139
#*# height3_pos = 14657.000,20532.000,20156.000
#*# height4 = 4.139
#*# height4_pos = 16242.000,16501.000,21244.000
#*# height5 = 4.139
#*# height5_pos = 19673.000,14988.000,19613.000
#*# height6 = 4.139
#*# height6_pos = 22375.000,16427.000,16214.000

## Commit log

2026-05-18 Add full project STL files
    [45 deg tower mount for sherpa extra heavy (3).stl, 45deg-tower-mount-for-sherpa extra-heavy.stl, BDP board mount-back.stl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]
2026-05-18 feat(chassis): clean up Chassis section and add README
    [BDP effector - bottom plate.stl, BDP effector - duct.stl, BDP effector - glue up jig.stl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]
2026-05-18 feat: update chassis image and add TC link
2026-05-19 feat: add documentation for effector
    [bottom-plate.stl, duct.stl, glue-up-jig.stl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]
2026-05-19 feat: add docs for sherpa extra lovely
    [45deg-tower-mount.stl, housing-core.stl, housing-front.stl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]
2026-05-25 fix: update chassis models and guide
    [bed-mount-base.stl, bed-mount-knob.stl, cable-guide-base.stl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]
2026-05-25 fix: add flying extruder plate files
    [flying-extruder-mount.stl]
2026-05-25 feat: update documents for motion system
    [MGN12 Rail-stopper (1).stl, carriage.stl, endstop-mount.stl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]
2026-05-25 feat: add documentation for PSU mount
    [endcap-ac.stl, endcap-dc.stl, mount-left.stl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]
2026-05-25 feat: Add BOM and image to README
2026-05-25 fix: add delta arms to bom
2026-05-25 fix: correct 2020 bom quantiy
2026-05-26 Update printer config and licensing
    [printer.cfg]
2026-05-26 feat: clarify CAD source and add RP action
    [frame_motor_2020.step, frame_top_2020.step]
2026-05-26 feat: add generated BOM workflow
    [chassis.csv, combined.csv, effector.csv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]
